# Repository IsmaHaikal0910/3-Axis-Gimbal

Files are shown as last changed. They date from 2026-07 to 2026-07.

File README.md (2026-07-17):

# Camera Gimbal — 3-Axis Stabilization for Smartphones & Cameras

> Custom-built 3-axis camera gimbal (STorM32 BGC + ESP32) with a self-designed 3D-printed frame, wireless shutter control, and a web dashboard for battery/BLE monitoring. Built for a Mechatronics lab project at Jade University of Applied Sciences.

---

## 🇬🇧 English

### Overview
This project is a fully custom 3-axis camera gimbal for smartphones and small action cameras, developed as part of the "Komplexlabor Mechatronik" course at Jade Hochschule Wilhelmshaven (Summer 2026). The goal was to design, build, and validate a handheld gimbal that stabilizes roll, pitch, and yaw in real time, using a mechanically optimized 3D-printed frame and an open, configurable electronics stack instead of a proprietary commercial system (e.g. DJI RS5).

### Key Features
- **3-axis active stabilization** (roll, pitch, yaw) via three iPower GM3506 brushless gimbal motors with AS5048A encoders
- **STorM32 v4.1** BGC controller + **NT IMU v4.2** for orientation sensing and PID-based motor control
- **ESP32** microcontroller handling joystick input, buttons, status LED, and wireless connectivity
- **WLAN/Bluetooth bridge**: a companion phone connects to the ESP32 over Wi-Fi and relays Bluetooth shutter commands to the camera
- **Custom HTML web interface** showing live battery percentage/voltage and providing remote shutter + Bluetooth scan controls
- Self-designed 3D-printed frame (P430 ABS+), removable 11.1 V / 3000 mAh LiPo battery, IP54-rated enclosure target
- Requirements list, circuit diagram, energy-flow diagram, and full verification & validation (V&V) test protocol

### Test Results (summary)
| Test | Result |
|---|---|
| Battery life (215 g payload) | ~2 hours |
| Reaction time (90° step) | 2.46 s (≈36.6°/s) |
| IMU drift (roll/pitch) | No measurable drift |
| Motor thermal | Uncritical after 10–15 min continuous load |
| TRL | 4, approaching 5 |

### Hardware
STorM32 v4.1, NT IMU v4.2, 3× iPower GM3506 gimbal motors, ESP32 (NodeMCU), analog joystick module, 2-button module, RGB status LED, 11.1 V 3000 mAh LiPo + balance charger. Full bill of materials with suppliers and cost is included in the lab report.

### Status & Outlook
The mechanical and electrical integration is complete; PID tuning (especially on the yaw axis) and full closed-loop real-time stabilization are ongoing. Planned next steps include C++/PlatformIO code refactoring with auto-reconnect, mechanical load testing of the screw connections, and empirical battery-life validation under real load.

---

## 🇩🇪 Deutsch

### Überblick
Dieses Projekt ist ein vollständig selbst entwickeltes 3-Achsen-Kamera-Gimbal für Smartphones und kleine Actioncams, entstanden im Rahmen des Komplexlabors Mechatronik an der Jade Hochschule Wilhelmshaven (Sommersemester 2026). Ziel war die Konstruktion, der Aufbau und die Validierung eines Handheld-Gimbals, das Roll-, Pitch- und Yaw-Bewegungen in Echtzeit ausgleicht — mit einem mechanisch optimierten, selbst konstruierten 3D-Druck-Rahmen und einer offenen, konfigurierbaren Elektronik statt eines proprietären kommerziellen Systems (z. B. DJI RS5).

### Hauptmerkmale
- **Aktive 3-Achsen-Stabilisierung** (Roll, Pitch, Yaw) über drei bürstenlose iPower-GM3506-Kardanmotoren mit AS5048A-Encodern
- **STorM32 v4.1** BGC-Controller + **NT IMU v4.2** zur Lageerfassung und PID-basierten Motorregelung
- **ESP32**-Mikrocontroller für Joystick-Eingabe, Taster, Status-LED und drahtlose Kommunikation
- **WLAN/Bluetooth-Brücke**: Ein Mobiltelefon verbindet sich per WLAN mit dem ESP32 und leitet Bluetooth-Auslösebefehle an die Kamera weiter
- **Eigenes HTML-Web-Interface** mit Live-Anzeige von Akkustand/Spannung sowie Fernsteuerung von Auslöser und Bluetooth-Suchlauf
- Selbst konstruierter 3D-Druck-Rahmen (P430 ABS+), entnehmbarer 11,1 V / 3000 mAh LiPo-Akku, Gehäuse ausgelegt auf IP54
- Anforderungsliste, Schaltplan, Energieflussdiagramm sowie ein vollständiges Verifikations- und Validierungs-Testprotokoll (V+V)

### Testergebnisse (Zusammenfassung)
| Test | Ergebnis |
|---|---|
| Akkulaufzeit (215 g Nutzlast) | ca. 2 Stunden |
| Reaktionszeit (90°-Schwenk) | 2,46 s (≈36,6°/s) |
| IMU-Drift (Roll/Pitch) | Keine messbare Drift |
| Motorerwärmung | Unkritisch nach 10–15 Min Dauerbetrieb |
| TRL | 4, an der Schwelle zu 5 |

### Hardware
STorM32 v4.1, NT IMU v4.2, 3× iPower-GM3506-Kardanmotoren, ESP32 (NodeMCU), analoges Joystick-Modul, 2-Tasten-Modul, RGB-Status-LED, 11,1 V 3000 mAh LiPo-Akku mit Balance-Ladegerät. Die vollständige Stückliste mit Lieferanten und Kosten befindet sich im Laborbericht.

### Status & Ausblick
Der mechanische und elektronische Aufbau ist abgeschlossen; die PID-Feinabstimmung (insbesondere der Yaw-Achse) sowie die vollständige Echtzeit-Stabilisierung im geschlossenen Regelkreis sind noch in Arbeit. Geplante nächste Schritte: Code-Refactoring in C++/PlatformIO mit automatischer Wiederverbindung, mechanischer Belastungstest der Schraubverbindungen sowie empirische Validierung der Akkulaufzeit unter realer Last.

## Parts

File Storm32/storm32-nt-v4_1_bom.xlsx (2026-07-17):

storm32-nt-v4 (_1)
index | qty | mounted | name(s) | description | type | value | voltage | tolerance | manufacturer | manufacturer code | jlcpcb
1 | 12 | Yes | C1, C2, C8, C9, ... | capacitor | 0402 (1005 metric) | 0.1uF | 16 | 20 | any | ceramic multilayer | C60474
2 | 2 | Yes | C3, C22 | capacitor | 1210 (3225 metric) | 10uF | 63 | 20 | any | ceramic multilayer | C13585
3 | 1 | Yes | C6 | tantalum capacitor | CASE A | 100uF | 6.3 | 20 | any | tantalum capacitor | C313517
4 | 1 | Yes | L1 | inductor | 4x4 | 10uH |  |  | any | any | C38117
5 | 1 | Yes | U1 | regulator | SOT23-6 | TPS54302 |  |  | Texas Instruments | TPS54302DDCR | C311983
6 | 1 | Yes | C4 | capacitor | 0603 (1608 metric) | 0.1uF | 50 | 10 | any | ceramic multilayer | C14663
7 | 2 | Yes | C5, C7 | capacitor | 0603 (1608 metric) | 10uF | 25 | 20 | any | ceramic multilayer | C19702
8 | 5 | Yes | R4, R6, R8, R9, ... | resistor | 0402 (1005 metric) | 10k | 50 | 1 | any | metal/carbon/thick | C25744
9 | 1 | Yes | R5 | resistor | 0402 (1005 metric) | 75k | 50 | 1 | any | metal/carbon/thick | C25798
10 | 1 | Yes | U3 | MCU | LQFP-64 | STM32F103RCT6 |  |  | STMicroelectronics | STM32F103RCT6 | C8323
11 | 1 | Yes | Q1 | resonator | 3213 | 8MHz |  |  | any | any | C341522
12 | 1 | Yes | LED1 | led | 0603 (1608 metric) | GREEN |  |  | Dialight | 598-8D80-107F | C84264
13 | 1 | Yes | LED2 | led | 0603 (1608 metric) | RED |  |  | Dialight | 598-8D10-107F | C90692
14 | 3 | Yes | D1, D2, D3 | diode | SOD-123 | PMEG3010ER |  |  | Nexperia | PMEG3010ER,115 | C456106
15 | 2 | Yes | J6, J7 | connector | 4-pin | SM04B-SRSS-TB |  |  | JST | SM04B-SRSS-TB(LF)(SN) | C160404
16 | 1 | Yes | J10 | connector | 3-pin | SM03B-SRSS-TB |  |  | JST | SM03B-SRSS-TB(LF)(SN) | C160403
17 | 1 | Yes | U4 | usb-uart | QFN-20 | CP2102N |  |  | Silicon Labs | CP2102N-A02-GQFN20R | C969913
18 | 1 | Yes | R7 | resistor | 0402 (1005 metric) | 1k5 | 50 | 1 | any | metal/carbon/thick | C25867
19 | 1 | Yes | R3 | resistor | 0402 (1005 metric) | 15k | 50 | 1 | any | metal/carbon/thick | C25756
20 | 5 | Yes | U7, U8, U9, U10, ... | driver | WSON-12 | DRV8839 |  |  | Texas Instruments | DRV8839DSSR | C128627
21 | 1 | Yes | U2 | regulator | SOT23-5 | XC6210B332MR |  |  | Torex | XC6210B332MR | C424705
22 | 3 | Yes | R1, R2, R13 | resistor | 0402 (1005 metric) | 2k2 | 50 | 1 | any | metal/carbon/thick | C25879
23 | 1 | Yes | J4 | connector | 7-pin | SM07B-SRSS-TB |  |  | JST | SM07B-SRSS-TB(LF)(SN) | C160393
24 | 1 | Yes | R14 | resistor | 0402 (1005 metric) | 4k7 | 50 | 1 | any | metal/carbon/thick | C25900
25 | 1 | Yes | U6 | xor | SOT23-5 | 74AHC1G86 |  |  | Texas Instruments | SN74AHC1G86DBVR | C7471
26 | 2 | Yes | C13, C15 | capacitor | 0402 (1005 metric) | 4.7uF | 6.3 | 20 | any | ceramic multilayer | C23733
27 | 1 | Yes | C12 | capacitor | 0402 (1005 metric) | 10nF | 16 | 10 | any | ceramic multilayer | C15195
28 | 1 | Yes | U5 | imu | SMD | ICM42688 |  |  | TDK InvenSense | ICM-42688-P | C1850418
29 | 1 | Yes | J3 | usb-c | smd/tht | usb-c |  |  | Dealon | USB-TYPE-C-16P | C668624
30 | 1 | Yes | J5 | connector | 5-pin | SM05B-SRSS-TB |  |  | JST | SM05B-SRSS-TB(LF)(SN) | C136657
31 | 2 | Yes | R10, R11 | resistor | 0402 (1005 metric) | 5k1 | 50 | 1 | any | metal/carbon/thick | C25905
32 | 1 | Yes | C10 | capacitor | 0402 (1005 metric) | 2.2uF | 6.3 | 20 | any | ceramic multilayer | C12530

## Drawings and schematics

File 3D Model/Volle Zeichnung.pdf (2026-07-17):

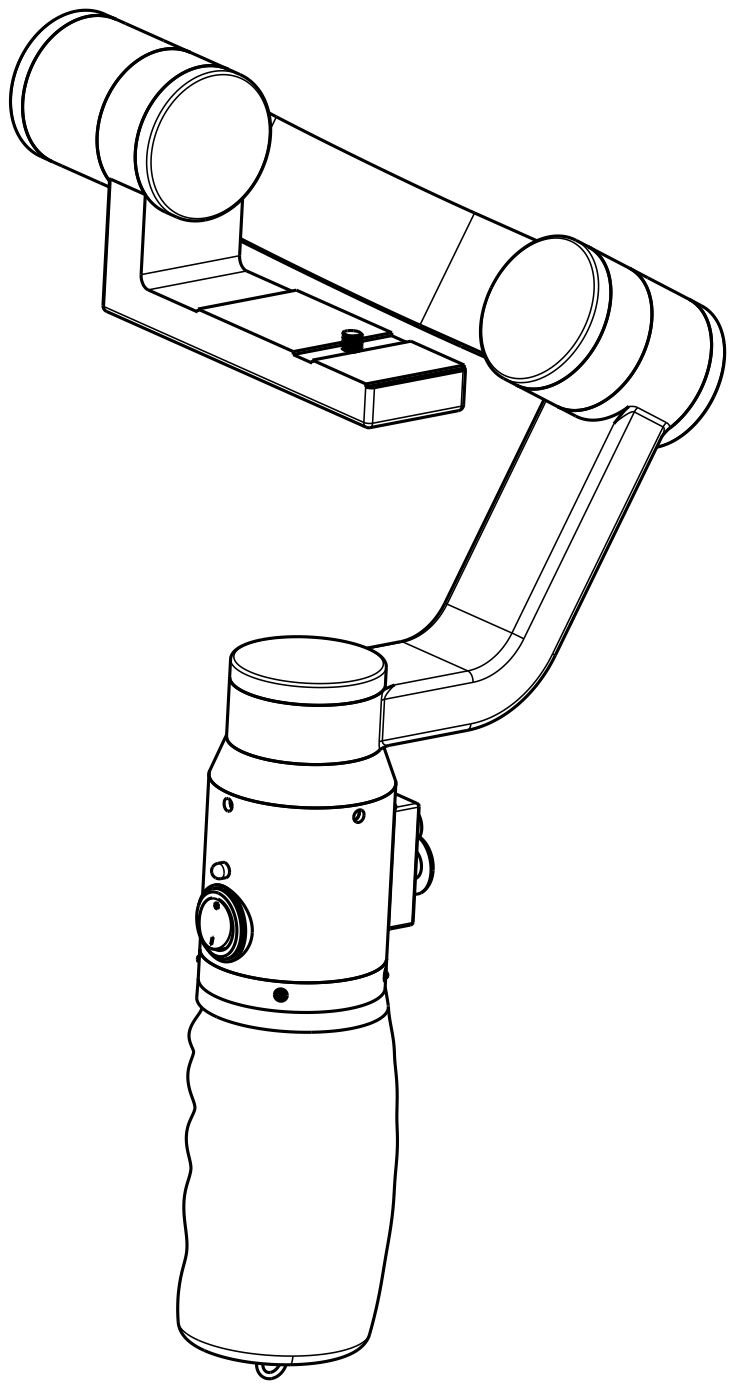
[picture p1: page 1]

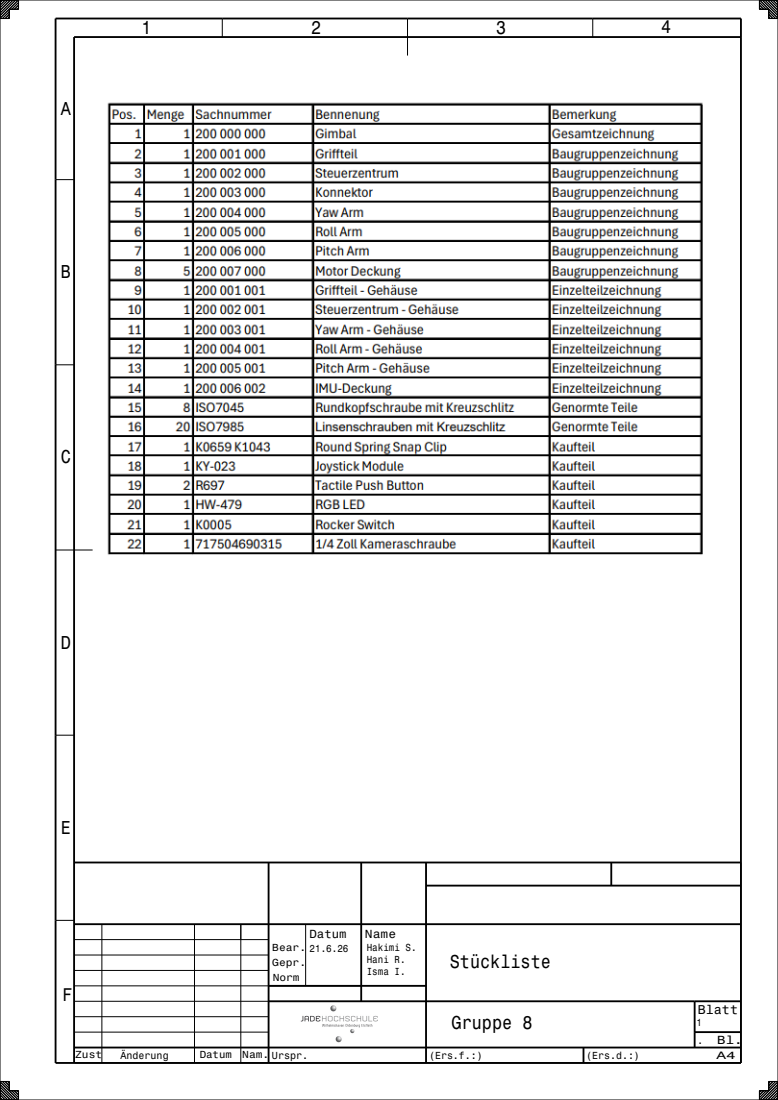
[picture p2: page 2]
Gruppe 8; Hakimi S. Hani R. Isma I.; Zust; Änderung; Datum; Nam. Urspr.

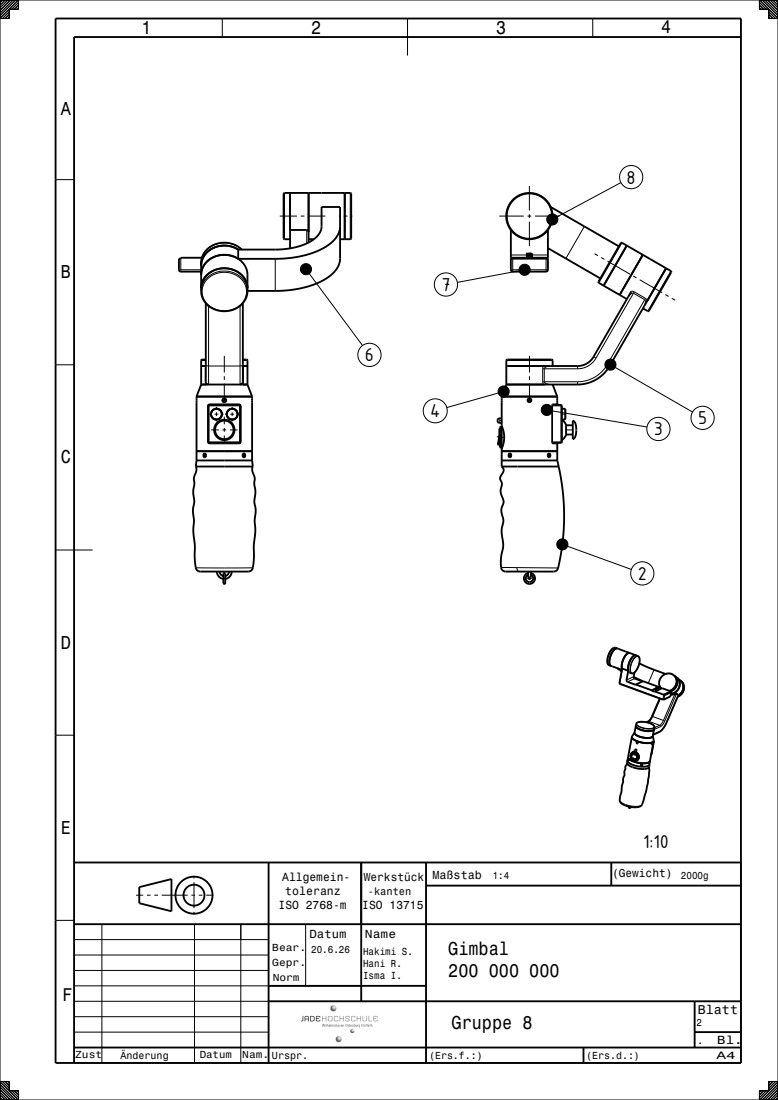
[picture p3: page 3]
ISO 2768-m; ISO 13715; (Gewicht) 2000g; Maßstab 1:4; Hakimi S. Hani R. Isma I.

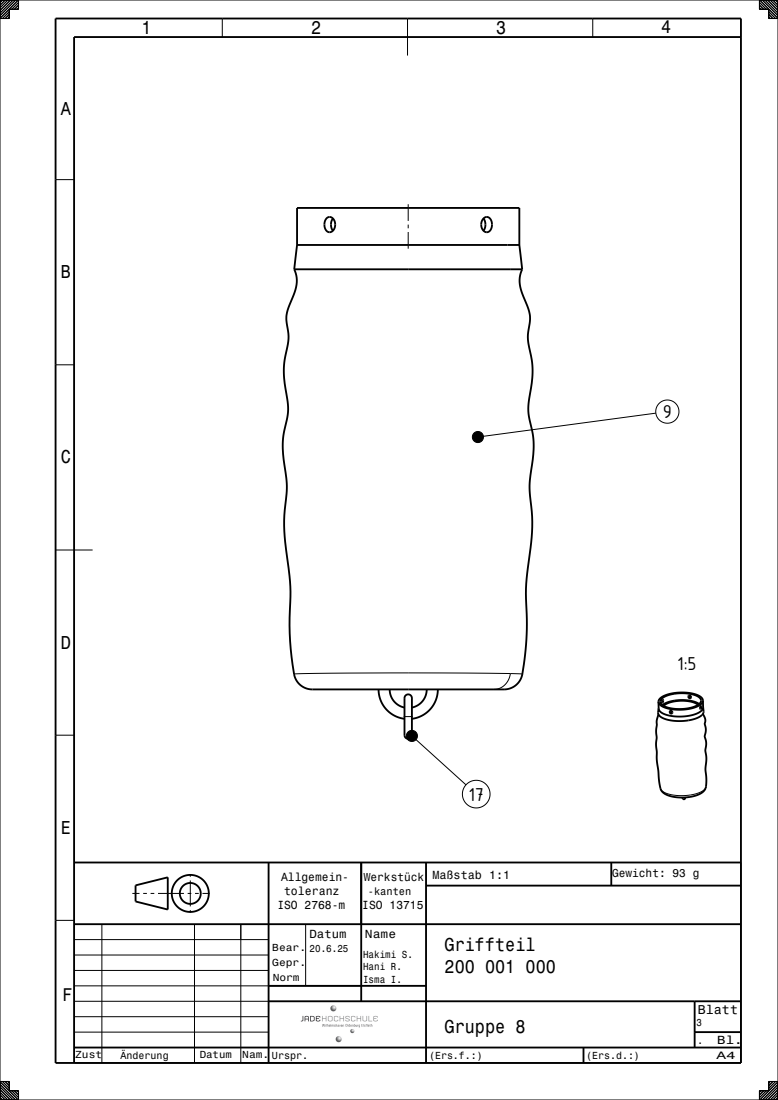
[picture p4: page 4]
ISO 2768-m; ISO 13715; Gewicht: 93 g; Maßstab 1:1; Hakimi S. Hani R. Isma I.

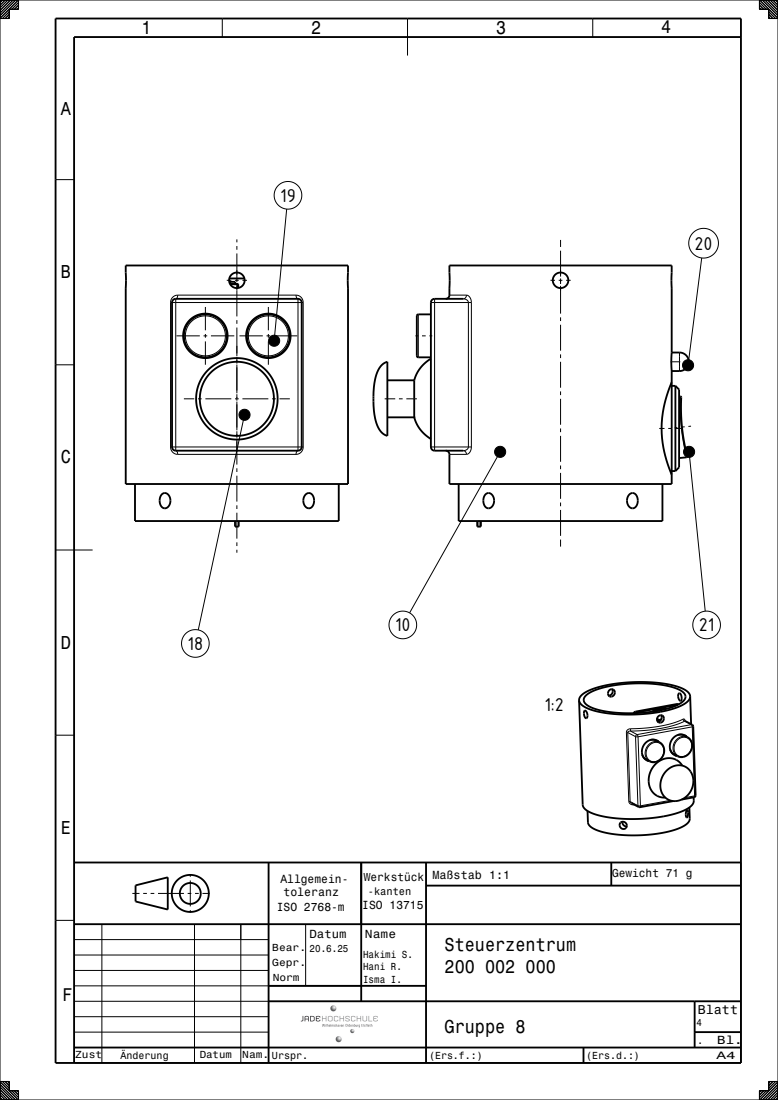
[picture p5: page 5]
ISO 2768-m; ISO 13715; Gewicht 71 g; Maßstab 1:1; Hakimi S. Hani R. Isma I.

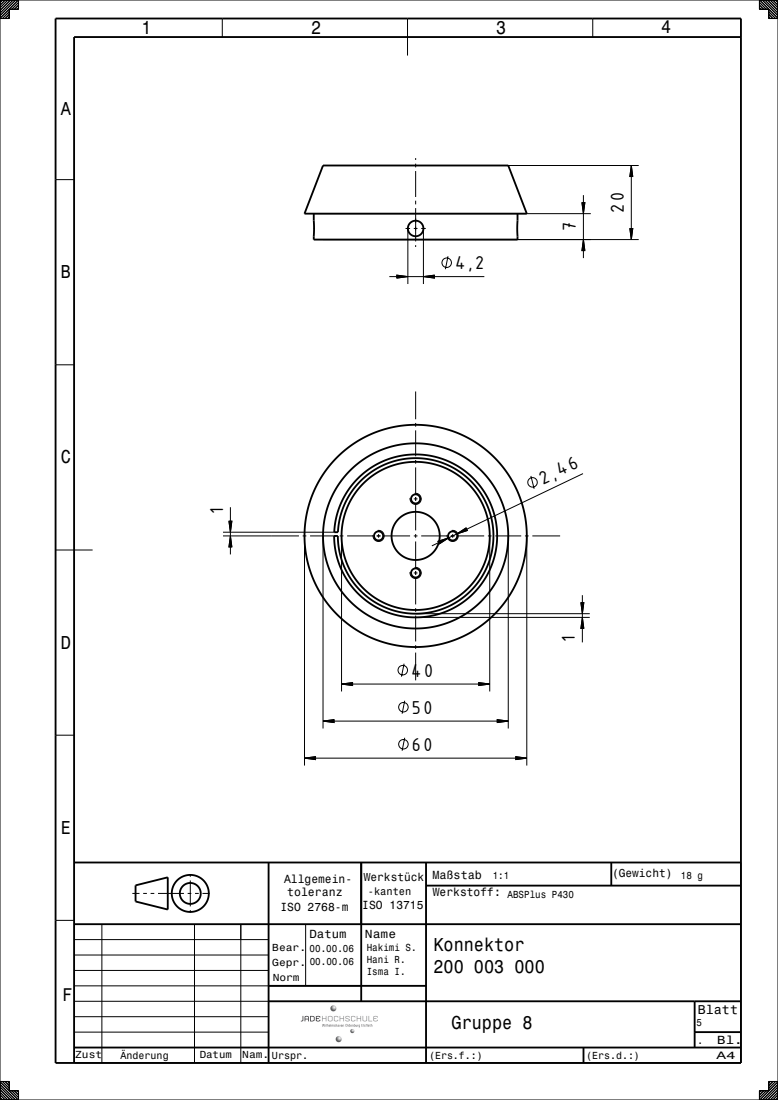
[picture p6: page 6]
ISO 2768-m; ISO 13715; (Gewicht) 18 g; Werkstoff: ABSPlus P430; Maßstab 1:1; Hakimi S. Hani R. Isma I.

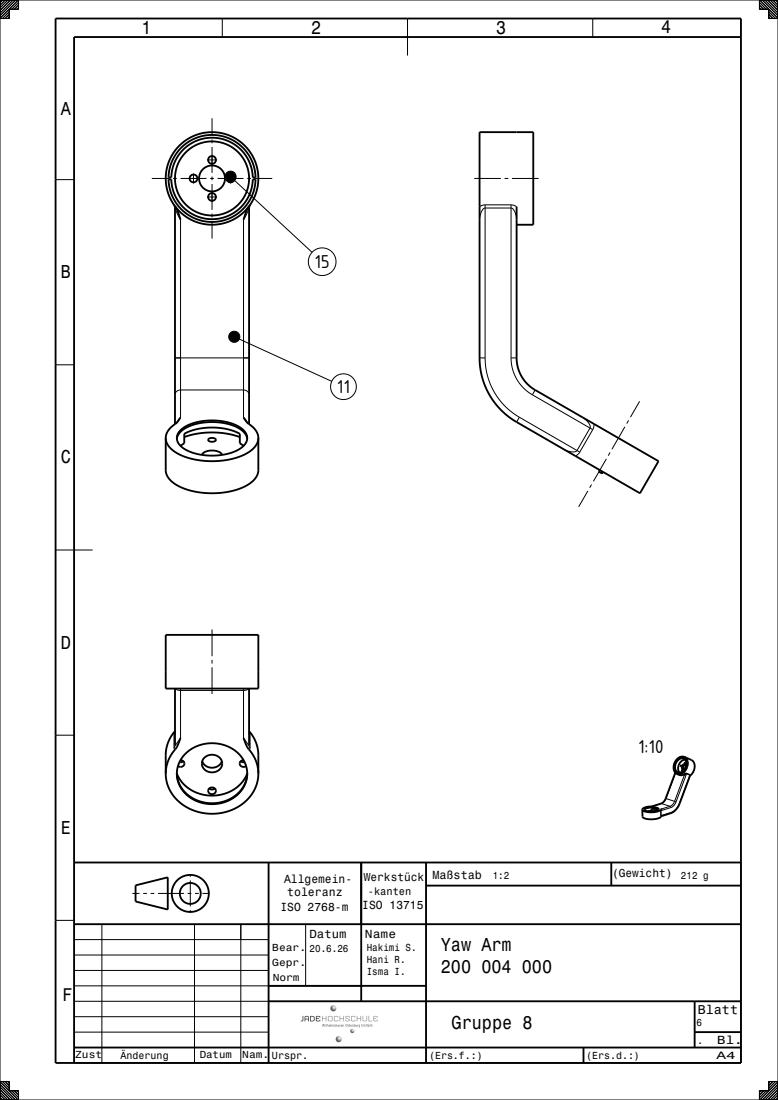
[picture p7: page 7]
ISO 2768-m; ISO 13715; (Gewicht) 212 g; Yaw Arm 200 004 000; Maßstab 1:2; Hakimi S. Hani R. Isma I.

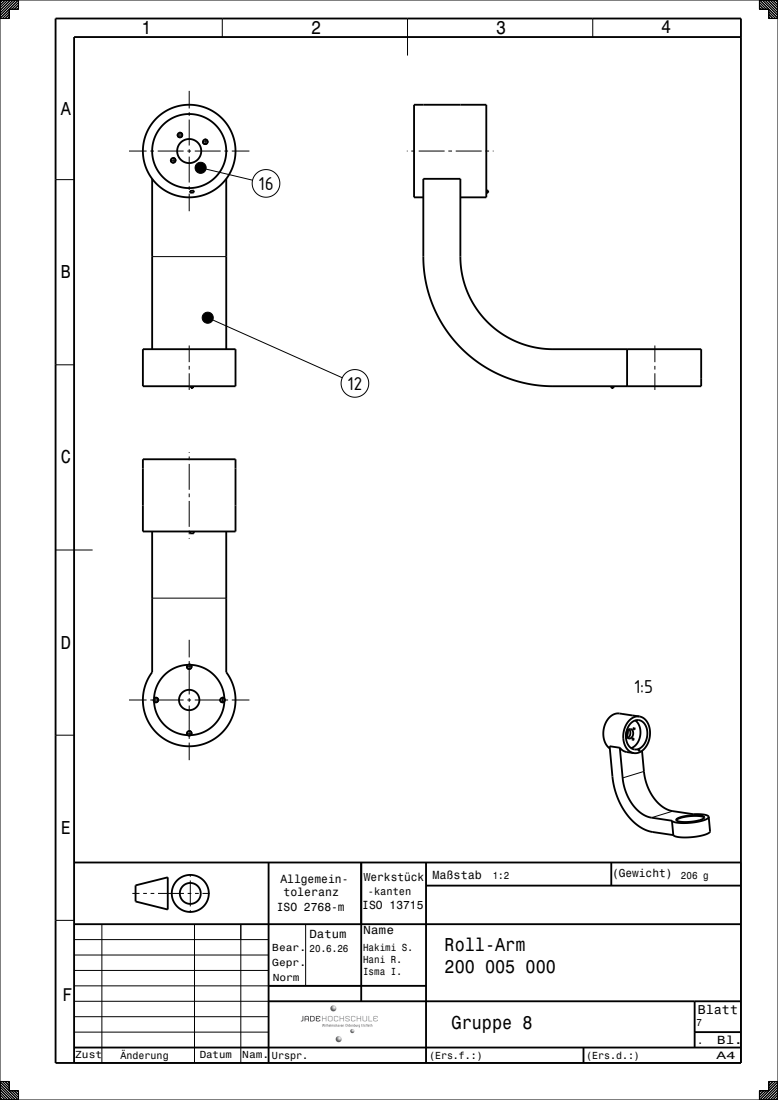
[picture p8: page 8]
ISO 2768-m; ISO 13715; (Gewicht) 206 g; Maßstab 1:2; Hakimi S. Hani R. Isma I.

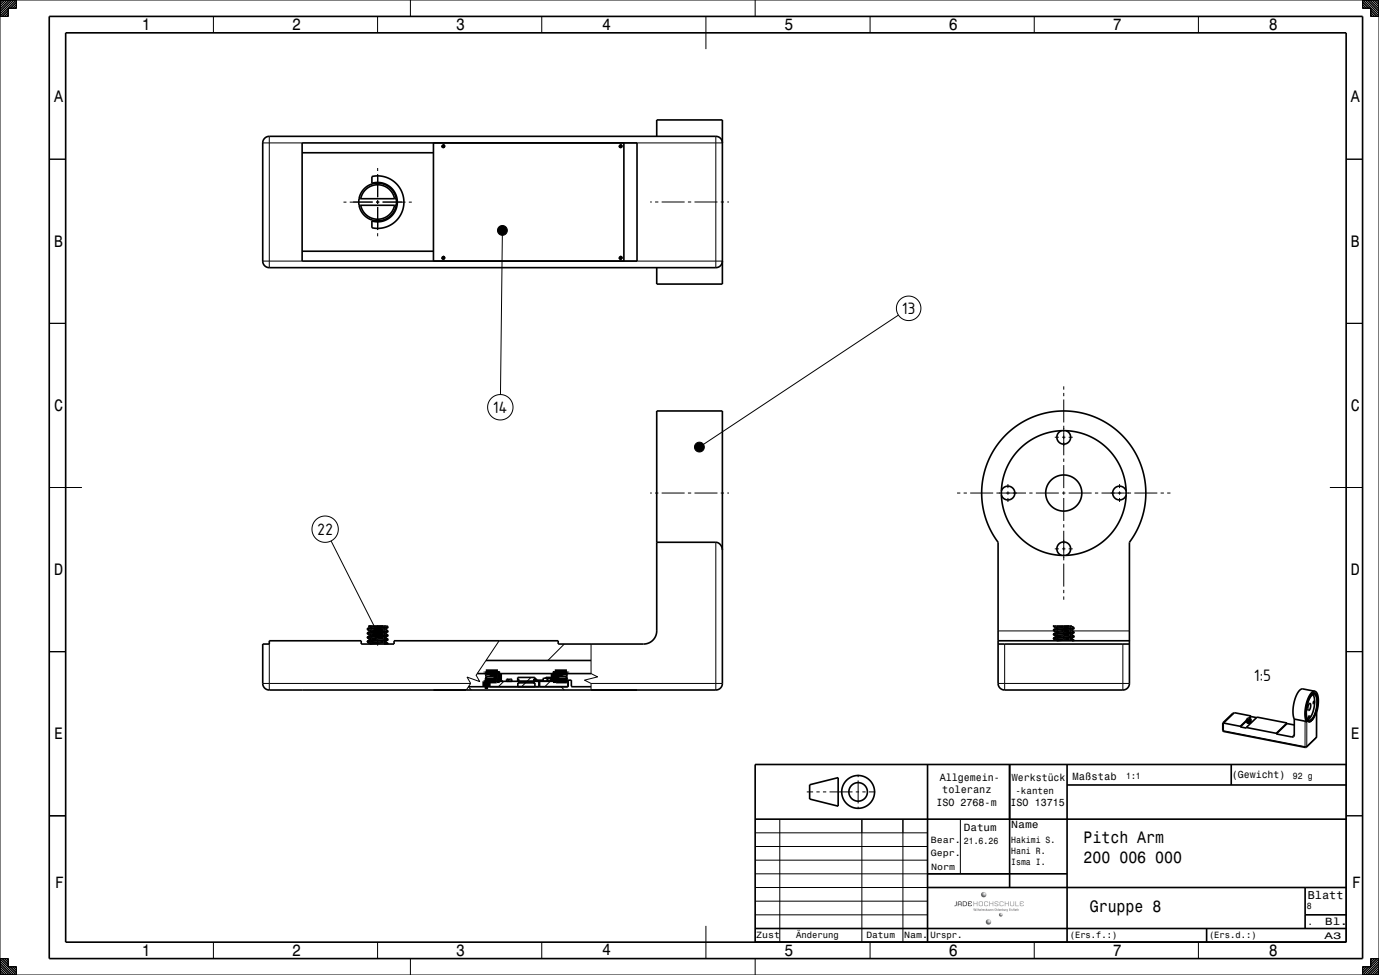
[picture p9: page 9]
ISO 2768-m; ISO 13715; (Gewicht) 92 g; Pitch Arm 200 006 000; Maßstab 1:1; Hakimi S. Hani R. Isma I.

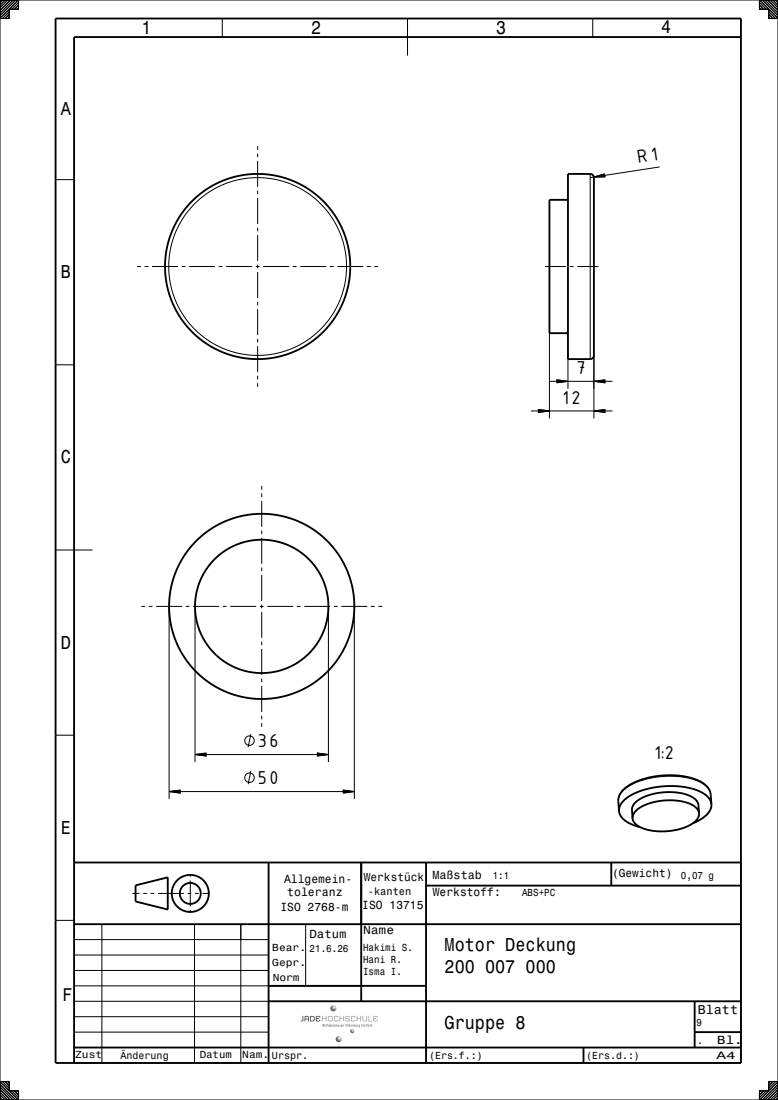
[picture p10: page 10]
ISO 2768-m; ISO 13715; (Gewicht) 0,07 g; Motor Deckung 200 007 000; Maßstab 1:1; Hakimi S. Hani R. Isma I.

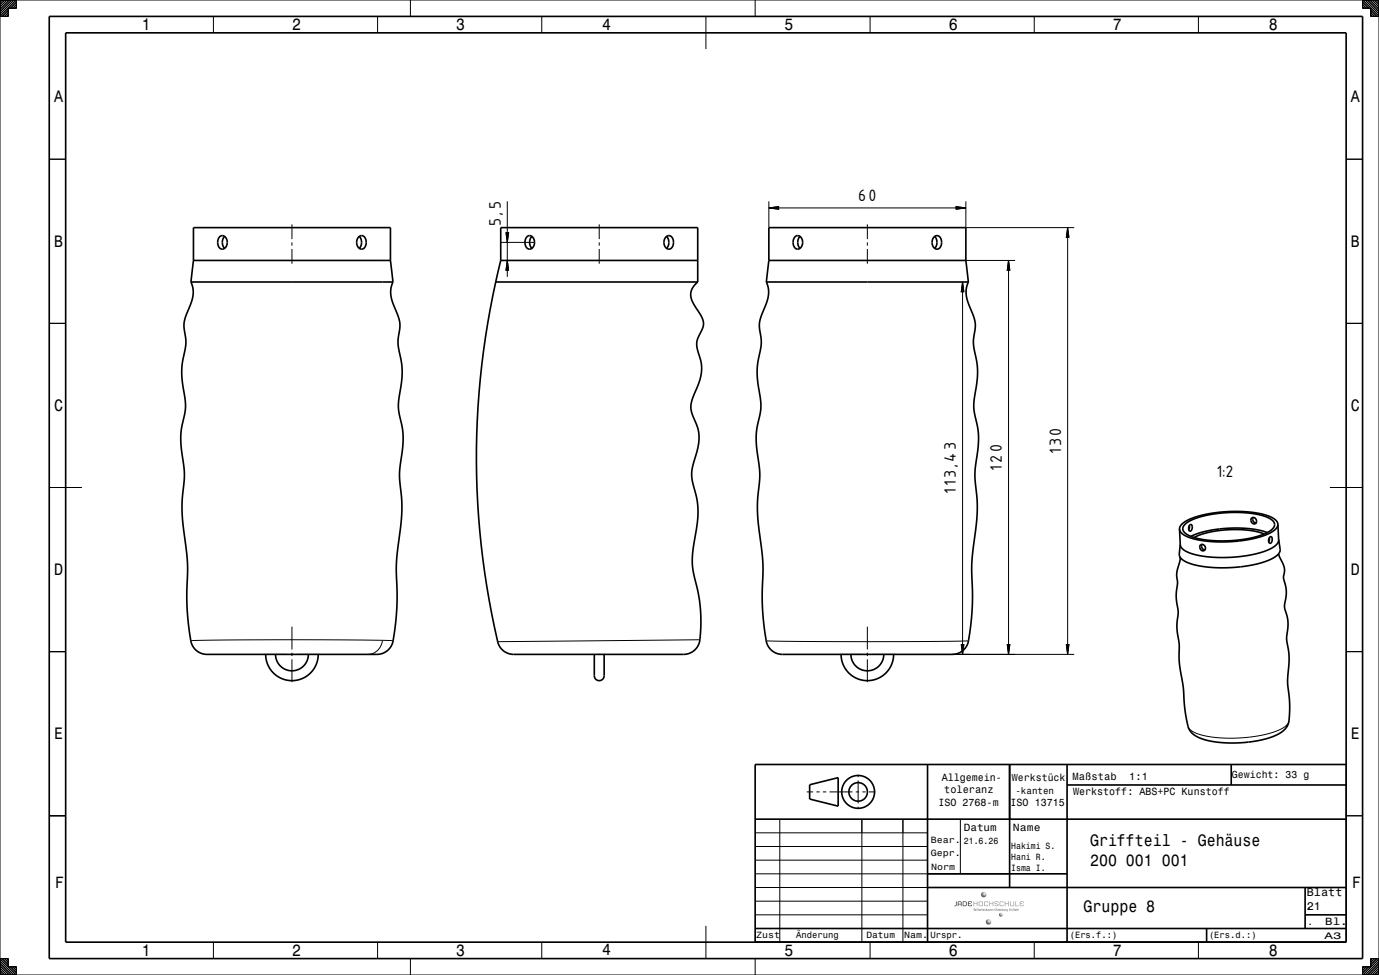
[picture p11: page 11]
ISO 2768-m; ISO 13715; Gewicht: 33 g

Maßstab 1:1
Werkstoff: ABS+PC Kunstoff

Bear. Gepr. Norm | Datum 21.6.26 | Name Hakimi S. Hani R. Isma I. | Griffteil - Gehäuse 200 001 001

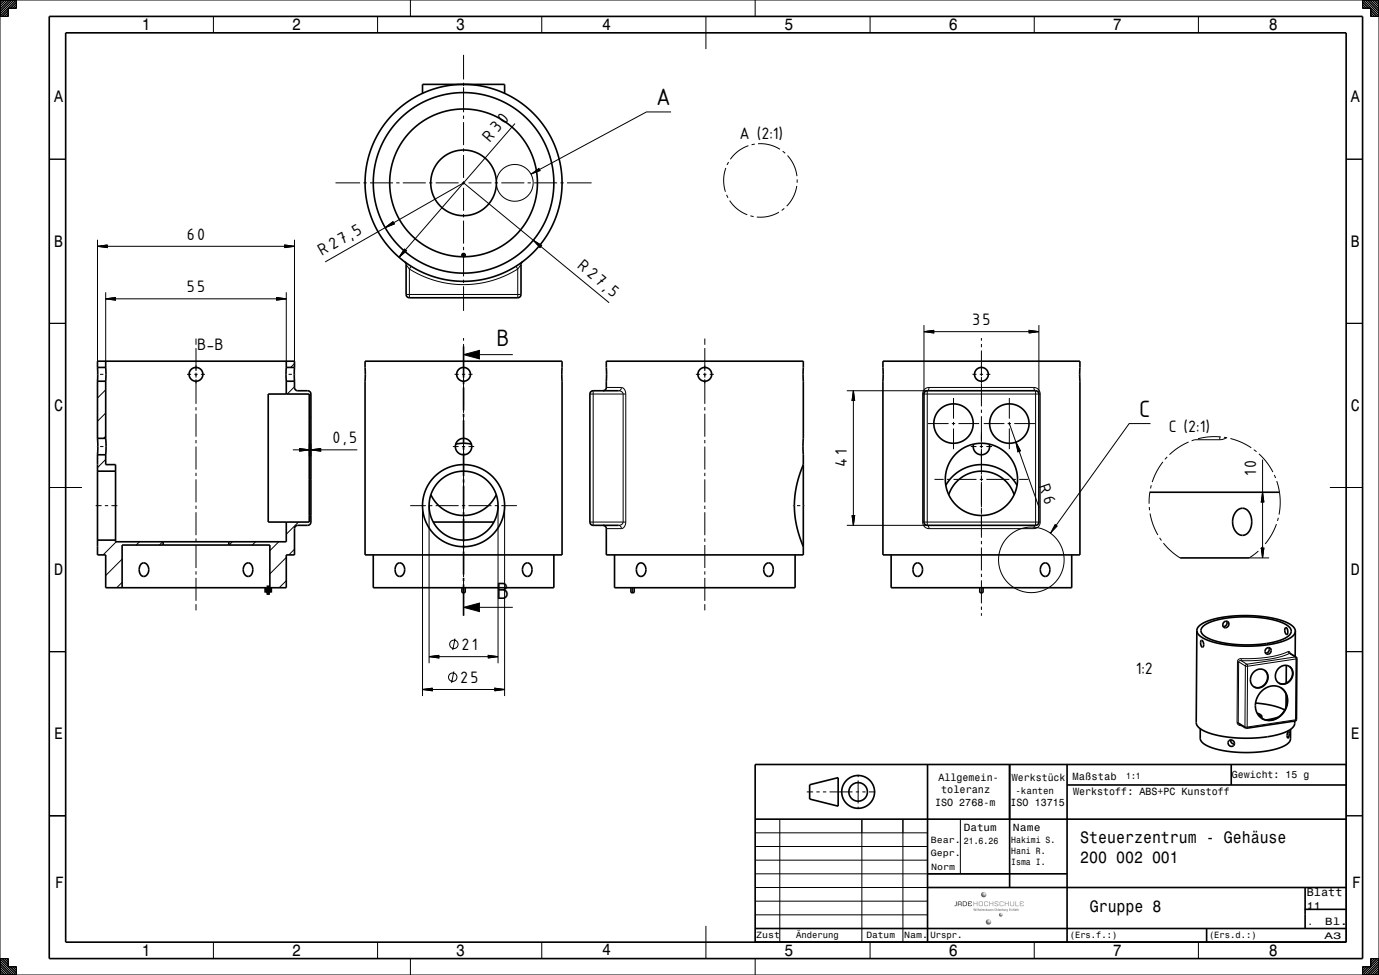
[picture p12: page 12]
ISO 2768-m; ISO 13715; Gewicht: 15 g; Steuerzentrum - Gehäuse 200 002 001; Hakimi S. Hani R. Isma I.

Maßstab 1:1
Werkstoff: ABS+PC Kunstoff

ISO 2768-m; ISO 13715; (Gewicht) 208g; Werkstoff:; ABSPlus P430; Maßstab 1:1; Hakimi S. Hani R. Isma I.

Yaw Arm - Gehäuse

ISO 2768-m; ISO 13715; (Gewicht) 126 g; Werkstoff:; ABS + PC Kunstoff; Maßstab 1:1

Bear. Gepr. Norm | Datum 02.06.25 | Name Hakimi S. Hani R. Isma I. | Roll-Arm Gehäuse 200 004 001

ISO 2768-m; ISO 13715; (Gewicht) 76 g; Werkstoff:; ABS+ PC; Maßstab 1:1; Hakimi S. Hani R. Isma I.

Pitch Arm - Gehäuse

ISO 2768-m; ISO 13715; (Gewicht) 0,6 g; Gruppe 8'; Maßstab 1:1; Hakimi S. Hani R. Isma I.

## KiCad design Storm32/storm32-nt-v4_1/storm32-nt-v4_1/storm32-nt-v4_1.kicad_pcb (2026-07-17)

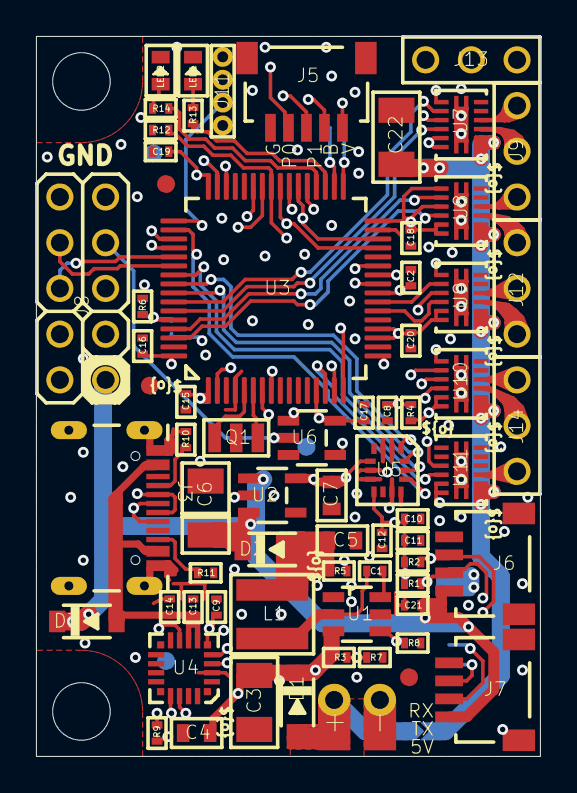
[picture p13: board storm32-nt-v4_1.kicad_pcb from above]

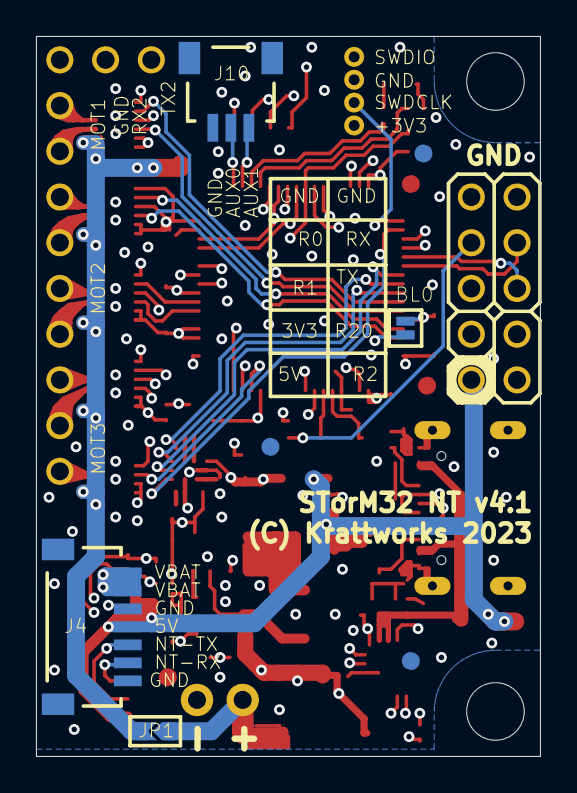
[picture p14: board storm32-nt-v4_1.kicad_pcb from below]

Board: 4 copper layers, 28.0 x 40.0 mm, 79 parts (7 on the bottom side), 69 nets.

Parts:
BL0: BOOT0; __SPARKFUN2_SJ_2S-NO
C1, C2, C8, C9, C11, C14, C16, C17, C18, C19, C20, C21: 0.1uF; 0402[1005-METRIC]
C3, C22: 10uF; 1206[3216-METRIC]
C4: 0.1uF; 0603[1608-METRIC]
C5, C7: 10uF; 0603[1608-METRIC]
C6: 100uF; 1206[3216-METRIC]-POL
C10: 2.2uF; 0402[1005-METRIC]
C12: 10nF; 0402[1005-METRIC]
C13, C15: 4.7uF; 0402[1005-METRIC]
D1, D2, D3: PMEG3010ER; SOD-123
FIDUCIAL1, FIDUCIAL2, FIDUCIAL3, FIDUCIAL4, FIDUCIAL5, FIDUCIAL6: FIDUCIAL
FRAMEBRD1: A5L-LOC
J1: +; 1
J2: -; 1
J3: TYPE-C-16P
J4: SM07B-SRSS-TB
J5: SM05B-SRSS-TB
J6, J7: SM04B-SRSS-TB
J8: HEADER; 2X5
J9, J12, J13, J14: HEADER_THT_2.54X1N_MALE-03
J10: SM03B-SRSS-TB
J11: HEADER_THT_1.27X1N_MALE-04
JP1: N/A; 0603[1608-METRIC]-0OHM-OFF
L1: 10uH; 4X4
LED1: GREEN; 0603[1608-METRIC]-DIODE
LED2: RED; 0603[1608-METRIC]-DIODE
Q1: 8MHz; RESONATOR
R1, R2, R13: 2k2; 0402[1005-METRIC]
R3: 15k; 0402[1005-METRIC]
R4, R6, R8, R9, R12: 10k; 0402[1005-METRIC]
R5: 75k; 0402[1005-METRIC]
R7: 1k5; 0402[1005-METRIC]
R10, R11: 5k1; 0402[1005-METRIC]
R14: 4k7; 0402[1005-METRIC]
U1: TPS54302; SOT-23-6
U2: XC6210B332MR; SOT-23-5
U3: STM32F103RCT6; QFP50P1200X1200X160-64N
U4: CP2102N; QFN-20
U5: ICM42688; LGA14
U6: 74AHC1G86; SOT-23-5
U7, U8, U9, U10, U11: DRV8839; WSON12
UNK_HOLE_0: dummyfp0
UNK_HOLE_1: dummyfp1

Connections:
+3V3: BL0.2, C7.P$1, C10.P$1, C11.P$1, C12.P$1, C15.P$1, C16.P$1, C17.P$1, C18.P$1, C19.P$1, C20.P$1, J5.1, J8.8, J11.1, R1.P$1, R2.P$1, R4.P$2, U2.5, U3.1, U3.13, U3.19, U3.20, U3.32, U3.48, U3.64, U5.5, U5.8, U6.5, U7.7, U7.9, U7.11, U7.12, U8.7, U8.9, U8.11, U8.12, U9.7, U9.9, U9.11, U9.12, U10.7, U10.9, U10.11, U10.12, U11.9, U11.11, U11.12
+5V: C6.P, C21.P$1, D2.C, D3.C, J4.4, J6.1, J7.1, J8.10, U2.1, U2.3
/CS: U3.50, U5.12
AUX0: J10.2, U3.33
AUX1: J10.1, U3.34
BUT: J5.2, U3.25
GND: C2.P$2, C3.P$2, C4.P$2, C5.P$2, C6.N, C7.P$2, C8.P$2, C9.P$2, C10.P$2, C11.P$2, C12.P$2, C13.P$2, C14.P$2, C15.P$2, C16.P$2, C17.P$2, C18.P$2, C19.P$2, C20.P$2, C21.P$2, C22.P$2, J2.1, J2.1A, J3.A1, J3.A12, J3.B1, J3.B12, J3.G1, J3.G2, J3.G3, J3.G4, J4.3, J4.7, J4.FIT@1, J4.FIT@2, J5.5, J5.FIT@1, J5.FIT@2, J6.4, J6.FIT@1, J6.FIT@2, J7.4, J7.FIT@1, J7.FIT@2, J8.1, J8.2, J10.3, J10.FIT@1, J10.FIT@2, J11.3, J13.1, LED1.C, LED2.C, Q1.G, R6.P$1, R7.P$1, R8.P$1, R10.P$2, R11.P$2, R12.P$2, U1.1, U2.2, U3.4, U3.12, U3.18, U3.28, U3.31, U3.47, U3.63, U4.3, U4.12, U5.2, U5.3, U5.6, U5.7, U5.10, U5.11, U6.3, U7.5, U7.6, U7.GND1, U7.GND2, U7.GND3, U7.GND4, U7.GND5, U8.5, U8.6, U8.GND1, U8.GND2, U8.GND3, U8.GND4, U8.GND5, U9.5, U9.6, U9.GND1, U9.GND2, U9.GND3, U9.GND4, U9.GND5, U10.5, U10.6, U10.GND1, U10.GND2, U10.GND3, U10.GND4, U10.GND5, U11.5, U11.6, U11.7, U11.8, U11.GND1, U11.GND2, U11.GND3, U11.GND4, U11.GND5
LED0: R13.P$2, U3.35
LED1: R14.P$2, U3.36
LIPO: C2.P$1, R3.P$1, R7.P$2, U3.24
M-A1: U3.58, U7.8
M-A2: U3.59, U7.10
M-A3: U3.61, U8.8
M-B1: U3.62, U8.10
M-B2: U3.23, U9.8
M-B3: U3.22, U9.10
M-C1: U3.26, U10.8
M-C2: U3.15, U10.10
M-C3: U3.14, U11.10
MISO: U3.56, U5.1
MOSI: U3.57, U5.14
unnamed: J3.A5, R10.P$1
unnamed: J3.B5, R11.P$1
unnamed: C1.P$1, L1.1, U1.2
unnamed: Q1.1, U3.6
unnamed: Q1.2, U3.5
unnamed: C8.P$1, R4.P$1, U3.7
unnamed: C1.P$2, U1.6
unnamed: LED1.A, R13.P$1
unnamed: J3.A6, J3.B6, U4.4
unnamed: J3.A7, J3.B7, U4.5
unnamed: C13.P$1, C14.P$1, D3.A, J3.A4, J3.A9, J3.B4, J3.B9, U4.7, U4.8
unnamed: R9.P$2, U4.9
unnamed: R5.P$1, R8.P$2, U1.4
unnamed: C22.P$1, JP1.P$2, U7.1, U7.2, U8.1, U8.2, U9.1, U9.2, U10.1, U10.2, U11.1, U11.2
unnamed: C5.P$1, D2.A, L1.2, R5.P$2
unnamed: LED2.A, R14.P$1
unnamed: J9.1, U7.4
unnamed: J9.2, U7.3
unnamed: J9.3, U8.4
unnamed: J12.1, U8.3
unnamed: J12.2, U9.4
unnamed: J12.3, U9.3
unnamed: J14.2, U10.3
unnamed: J14.1, U10.4
unnamed: BL0.1, R6.P$2, U3.60
unnamed: J14.3, U11.3
NT_RX: J4.6, J6.3, J7.3, R2.P$2, U3.52
NT_TX: J4.5, J6.2, J7.2, R1.P$2, U3.51
POT0: J5.4, U3.27
POT1: J5.3, U3.8
RC0/RX3: U3.30, U3.38, U6.4
RC2-0: J8.7, U3.39
RC-0: J8.4, U6.2
RC-1: J8.6, U3.29, U3.40
RC-2: J8.9, U3.37
RX1: U3.43, U4.18
RX2: J13.2, U3.17
RX5: J8.3, U3.54
SCK: U3.55, U5.13
SWC: J11.2, U3.49
SWD: J11.4, U3.46
TX1: U3.42, U4.17
TX2: J13.3, U3.16
TX5: J8.5, U3.53
USB_DETECT: C9.P$1, R9.P$1, U3.2, U4.6
VBAT: C3.P$1, C4.P$1, D1.C, J4.1, J4.2, R3.P$2, U1.3
VIN: D1.A, J1.1, J1.1A, JP1.P$1
XOR: R12.P$1, U3.41, U6.1

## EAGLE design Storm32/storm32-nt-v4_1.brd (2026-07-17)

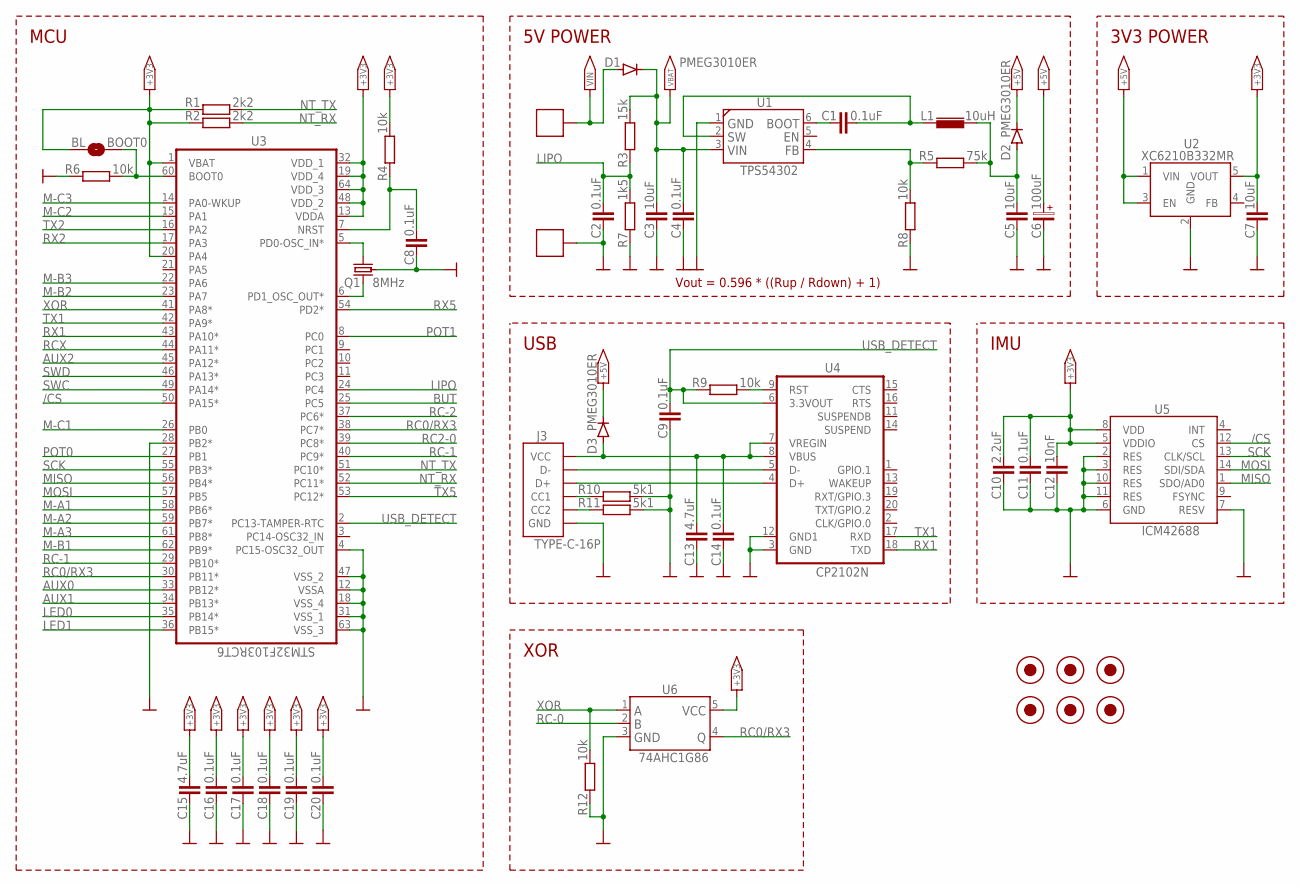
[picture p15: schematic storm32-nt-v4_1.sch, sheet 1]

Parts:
BL: BOOT0; __SPARKFUN2_SJ_2S-NO
C1, C2, C8, C9, C11, C14, C16, C17, C18, C19, C20: 0.1uF; 0402[1005-METRIC]
C3: 10uF; 1206[3216-METRIC]; VOLTAGE 63; MOUSER 81-GRM32ER71J106MA2L
C4: 0.1uF; 0603[1608-METRIC]
C5, C7: 10uF; 0603[1608-METRIC]
C6: 100uF; 1206[3216-METRIC]-POL
C10: 2.2uF; 0402[1005-METRIC]
C12: 10nF; 0402[1005-METRIC]
C13, C15: 4.7uF; 0402[1005-METRIC]
D1, D2, D3: PMEG3010ER; SOD-123
FIDUCIAL1, FIDUCIAL2, FIDUCIAL3, FIDUCIAL4, FIDUCIAL5, FIDUCIAL6: FIDUCIAL
J1: +; 1
J2: -; 1
J3: TYPE-C-16P
L1: 10uH; 4X4
Q1: 8MHz; RESONATOR
R1, R2: 2k2; 0402[1005-METRIC]
R3: 15k; 0402[1005-METRIC]
R4, R6, R8, R9, R12: 10k; 0402[1005-METRIC]
R5: 75k; 0402[1005-METRIC]
R7: 1k5; 0402[1005-METRIC]
R10, R11: 5k1; 0402[1005-METRIC]
U1: TPS54302; SOT-23-6
U2: XC6210B332MR; SOT-23-5
U3: STM32F103RCT6; QFP50P1200X1200X160-64N
U4: CP2102N; QFN-20
U5: ICM42688; LGA14
U6: 74AHC1G86; SOT-23-5

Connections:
+3V3: BL.2, C7.P$1 (1), C10.P$1 (1), C11.P$1 (1), C12.P$1 (1), C15.P$1 (1), C16.P$1 (1), C17.P$1 (1), C18.P$1 (1), C19.P$1 (1), C20.P$1 (1), R1.P$1, R2.P$1, R4.P$2, U2.5 (VOUT), U3.1 (VBAT), U3.13 (VDDA), U3.19 (VDD_4), U3.20 (PA4), U3.32 (VDD_1), U3.48 (VDD_2), U3.64 (VDD_3), U5.5 (VDDIO), U5.8 (VDD), U6.5; also elsewhere on the board
+5V: C6.P, D2.C, D3.C, U2.1 (VIN), U2.3 (EN); also elsewhere on the board
/CS: U3.50 (PA15*), U5.12 (CS)
AUX0: U3.33 (PB12*); also elsewhere on the board
AUX1: U3.34 (PB13*); also elsewhere on the board
AUX2: U3.45 (PA12*)
BUT: U3.25 (PC5); also elsewhere on the board
GND: C2.P$2 (2), C3.P$2 (2), C4.P$2 (2), C5.P$2 (2), C6.N, C7.P$2 (2), C8.P$2 (2), C9.P$2 (2), C10.P$2 (2), C11.P$2 (2), C12.P$2 (2), C13.P$2 (2), C14.P$2 (2), C15.P$2 (2), C16.P$2 (2), C17.P$2 (2), C18.P$2 (2), C19.P$2 (2), C20.P$2 (2), J2.1, J2.1A, J3.A1 (GND), J3.A12 (GND), J3.B1 (GND), J3.B12 (GND), J3.G1 (GND), J3.G2 (GND), J3.G3 (GND), J3.G4 (GND), Q1.G (GND), R6.P$1, R7.P$1, R8.P$1, R10.P$2, R11.P$2, R12.P$2, U1.1, U2.2 (GND), U3.4 (PC15-OSC32_OUT), U3.12 (VSSA), U3.18 (VSS_4), U3.28 (PB2*), U3.31 (VSS_1), U3.47 (VSS_2), U3.63 (VSS_3), U4.3 (GND), U4.12 (GND1), U5.2 (RES), U5.3 (RES), U5.6 (GND), U5.7 (RESV), U5.10 (RES), U5.11 (RES), U6.3; also elsewhere on the board
LED0: U3.35 (PB14*); also elsewhere on the board
LED1: U3.36 (PB15*); also elsewhere on the board
LIPO: C2.P$1 (1), R3.P$1, R7.P$2, U3.24 (PC4)
M-A1: U3.58 (PB6*); also elsewhere on the board
M-A2: U3.59 (PB7*); also elsewhere on the board
M-A3: U3.61 (PB8*); also elsewhere on the board
M-B1: U3.62 (PB9*); also elsewhere on the board
M-B2: U3.23 (PA7); also elsewhere on the board
M-B3: U3.22 (PA6); also elsewhere on the board
M-C1: U3.26 (PB0); also elsewhere on the board
M-C2: U3.15 (PA1); also elsewhere on the board
M-C3: U3.14 (PA0-WKUP); also elsewhere on the board
MISO: U3.56 (PB4*), U5.1 (SDO/AD0)
MOSI: U3.57 (PB5), U5.14 (SDI/SDA)
unnamed: J3.A5 (CC1), R10.P$1
unnamed: J3.B5 (CC2), R11.P$1
unnamed: C1.P$1 (1), L1.1, U1.2
unnamed: Q1.1, U3.6 (PD1_OSC_OUT*)
unnamed: Q1.2, U3.5 (PD0-OSC_IN*)
unnamed: C8.P$1 (1), R4.P$1, U3.7 (NRST)
unnamed: C1.P$2 (2), U1.6
unnamed: J3.A6 (D+), J3.B6 (D+), U4.4 (D+)
unnamed: J3.A7 (D-), J3.B7 (D-), U4.5 (D-)
unnamed: C13.P$1 (1), C14.P$1 (1), D3.A, J3.A4 (VCC), J3.A9 (VCC), J3.B4 (VCC), J3.B9 (VCC), U4.7 (VREGIN), U4.8 (VBUS)
unnamed: R9.P$2, U4.9 (RST)
unnamed: R5.P$1, R8.P$2, U1.4
unnamed: C5.P$1 (1), D2.A, L1.2, R5.P$2
unnamed: BL.1, R6.P$2, U3.60 (BOOT0)
NT_RX: R2.P$2, U3.52 (PC11*); also elsewhere on the board
NT_TX: R1.P$2, U3.51 (PC10*); also elsewhere on the board
POT0: U3.27 (PB1); also elsewhere on the board
POT1: U3.8 (PC0); also elsewhere on the board
RC0/RX3: U3.30 (PB11*), U3.38 (PC7*), U6.4
RC2-0: U3.39 (PC8*); also elsewhere on the board
RC-0: U6.2; also elsewhere on the board
RC-1: U3.29 (PB10*), U3.40 (PC9*); also elsewhere on the board
RC-2: U3.37 (PC6*); also elsewhere on the board
RCX: U3.44 (PA11*)
RX1: U3.43 (PA10*), U4.18 (TXD)
RX2: U3.17 (PA3); also elsewhere on the board
RX5: U3.54 (PD2*); also elsewhere on the board
SCK: U3.55 (PB3*), U5.13 (CLK/SCL)
SWC: U3.49 (PA14*); also elsewhere on the board
SWD: U3.46 (PA13*); also elsewhere on the board
TX1: U3.42 (PA9*), U4.17 (RXD)
TX2: U3.16 (PA2); also elsewhere on the board
TX5: U3.53 (PC12*); also elsewhere on the board
USB_DETECT: C9.P$1 (1), R9.P$1, U3.2 (PC13-TAMPER-RTC), U4.6 (3.3VOUT)
VBAT: C3.P$1 (1), C4.P$1 (1), D1.C, R3.P$2, U1.3; also elsewhere on the board
VIN: D1.A, J1.1, J1.1A; also elsewhere on the board
XOR: R12.P$1, U3.41 (PA8*), U6.1

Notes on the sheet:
Vout = 0.596 * ((Rup / Rdown) + 1)
5V POWER
USB
3V3 POWER
MCU
IMU
XOR

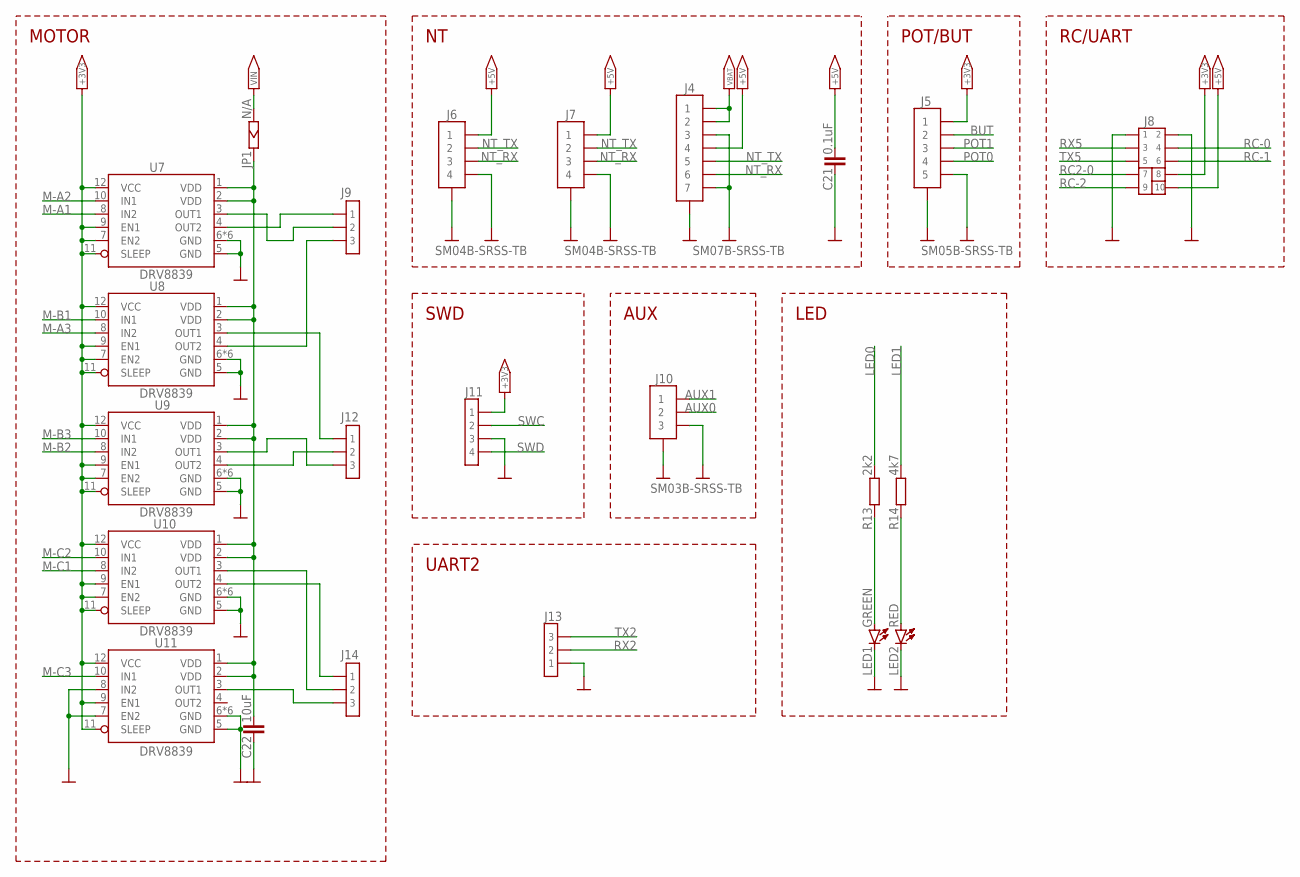
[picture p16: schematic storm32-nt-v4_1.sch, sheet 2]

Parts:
C21: 0.1uF; 0402[1005-METRIC]
C22: 10uF; 1206[3216-METRIC]; VOLTAGE 63; MOUSER 81-GRM32ER71J106MA2L
J4: SM07B-SRSS-TB
J5: SM05B-SRSS-TB
J6, J7: SM04B-SRSS-TB
J8: HEADER; 2X5
J9, J12, J13, J14: HEADER_THT_2.54X1N_MALE-03-2.54-2.54; HEADER_THT_2.54X1N_MALE-03
J10: SM03B-SRSS-TB
J11: HEADER_THT_1.27X1N_MALE-04-1.27-1.27; HEADER_THT_1.27X1N_MALE-04
JP1: N/A; 0603[1608-METRIC]-0OHM-OFF
LED1: GREEN; 0603[1608-METRIC]-DIODE
LED2: RED; 0603[1608-METRIC]-DIODE
R13: 2k2; 0402[1005-METRIC]
R14: 4k7; 0402[1005-METRIC]
U7, U8, U9, U10, U11: DRV8839; WSON12

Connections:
+3V3: J5.1, J8.8, J11.1, U7.7 (EN2), U7.9 (EN1), U7.11 (SLEEP), U7.12 (VCC), U8.7 (EN2), U8.9 (EN1), U8.11 (SLEEP), U8.12 (VCC), U9.7 (EN2), U9.9 (EN1), U9.11 (SLEEP), U9.12 (VCC), U10.7 (EN2), U10.9 (EN1), U10.11 (SLEEP), U10.12 (VCC), U11.9 (EN1), U11.11 (SLEEP), U11.12 (VCC); also elsewhere on the board
+5V: C21.P$1 (1), J4.4, J6.1, J7.1, J8.10; also elsewhere on the board
AUX0: J10.2; also elsewhere on the board
AUX1: J10.1; also elsewhere on the board
BUT: J5.2; also elsewhere on the board
GND: C21.P$2 (2), C22.P$2 (2), J4.3, J4.7, J4.FIT@1, J4.FIT@2, J5.5, J5.FIT@1, J5.FIT@2, J6.4, J6.FIT@1, J6.FIT@2, J7.4, J7.FIT@1, J7.FIT@2, J8.1, J8.2, J10.3, J10.FIT@1, J10.FIT@2, J11.3, J13.1, LED1.C, LED2.C, U7.5 (GND), U7.6 (GND), U7.GND1 (GND), U7.GND2 (GND), U7.GND3 (GND), U7.GND4 (GND), U7.GND5 (GND), U8.5 (GND), U8.6 (GND), U8.GND1 (GND), U8.GND2 (GND), U8.GND3 (GND), U8.GND4 (GND), U8.GND5 (GND), U9.5 (GND), U9.6 (GND), U9.GND1 (GND), U9.GND2 (GND), U9.GND3 (GND), U9.GND4 (GND), U9.GND5 (GND), U10.5 (GND), U10.6 (GND), U10.GND1 (GND), U10.GND2 (GND), U10.GND3 (GND), U10.GND4 (GND), U10.GND5 (GND), U11.5 (GND), U11.6 (GND), U11.7 (EN2), U11.8 (IN2), U11.GND1 (GND), U11.GND2 (GND), U11.GND3 (GND), U11.GND4 (GND), U11.GND5 (GND); also elsewhere on the board
LED0: R13.P$2; also elsewhere on the board
LED1: R14.P$2; also elsewhere on the board
M-A1: U7.8 (IN2); also elsewhere on the board
M-A2: U7.10 (IN1); also elsewhere on the board
M-A3: U8.8 (IN2); also elsewhere on the board
M-B1: U8.10 (IN1); also elsewhere on the board
M-B2: U9.8 (IN2); also elsewhere on the board
M-B3: U9.10 (IN1); also elsewhere on the board
M-C1: U10.8 (IN2); also elsewhere on the board
M-C2: U10.10 (IN1); also elsewhere on the board
M-C3: U11.10 (IN1); also elsewhere on the board
unnamed: LED1.A, R13.P$1
unnamed: C22.P$1 (1), JP1.P$2, U7.1 (VDD), U7.2 (VDD), U8.1 (VDD), U8.2 (VDD), U9.1 (VDD), U9.2 (VDD), U10.1 (VDD), U10.2 (VDD), U11.1 (VDD), U11.2 (VDD)
unnamed: LED2.A, R14.P$1
unnamed: J9.1, U7.4 (OUT2)
unnamed: J9.2, U7.3 (OUT1)
unnamed: J9.3, U8.4 (OUT2)
unnamed: J12.1, U8.3 (OUT1)
unnamed: J12.2, U9.4 (OUT2)
unnamed: J12.3, U9.3 (OUT1)
unnamed: J14.2, U10.3 (OUT1)
unnamed: J14.1, U10.4 (OUT2)
unnamed: J14.3, U11.3 (OUT1)
NT_RX: J4.6, J6.3, J7.3; also elsewhere on the board
NT_TX: J4.5, J6.2, J7.2; also elsewhere on the board
POT0: J5.4; also elsewhere on the board
POT1: J5.3; also elsewhere on the board
RC2-0: J8.7; also elsewhere on the board
RC-0: J8.4; also elsewhere on the board
RC-1: J8.6; also elsewhere on the board
RC-2: J8.9; also elsewhere on the board
RX2: J13.2; also elsewhere on the board
RX5: J8.3; also elsewhere on the board
SWC: J11.2; also elsewhere on the board
SWD: J11.4; also elsewhere on the board
TX2: J13.3; also elsewhere on the board
TX5: J8.5; also elsewhere on the board
VBAT: J4.1, J4.2; also elsewhere on the board
VIN: JP1.P$1; also elsewhere on the board

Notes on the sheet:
MOTOR
POT/BUT
SWD
AUX
UART2
LED
RC/UART

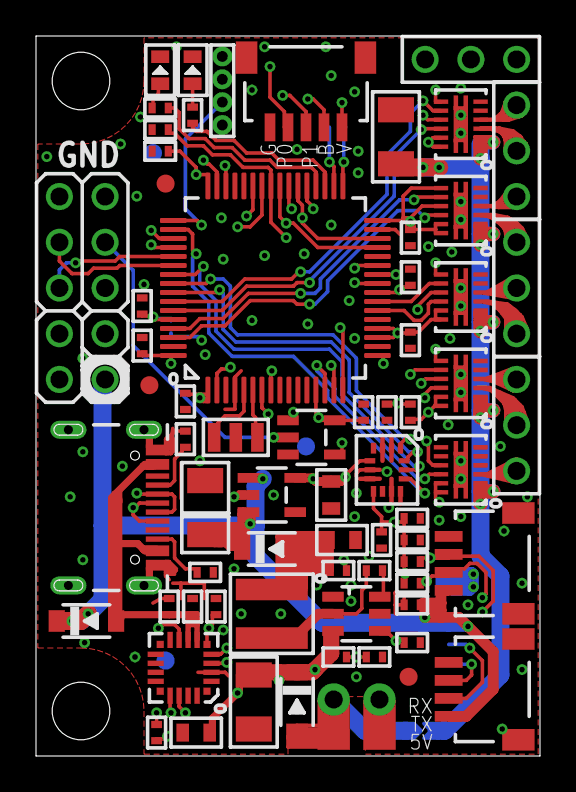
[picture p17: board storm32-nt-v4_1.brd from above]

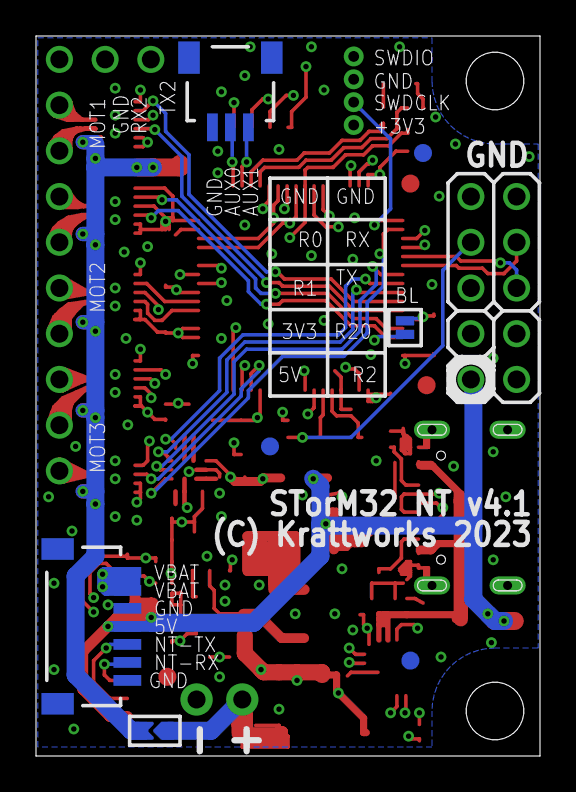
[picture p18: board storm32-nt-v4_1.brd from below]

Board: 4 copper layers, 28.0 x 40.0 mm, 77 parts (7 on the bottom side), 69 nets.

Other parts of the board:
FRAMEBRD1: A5L-LOC

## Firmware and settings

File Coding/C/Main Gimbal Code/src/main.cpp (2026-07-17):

#include <Arduino.h>
#include <HardwareSerial.h>
#include <BLEDevice.h>
#include <BLEUtils.h>
#include <BLEScan.h>
#include <BLEAdvertisedDevice.h>
#include <BLEClient.h>
#include <BLESecurity.h>
#include <WiFi.h>
#include <WebServer.h>
#include <Preferences.h>
#include <nvs_flash.h>
#include "STorM32_lib.h"

HardwareSerial storm32(1);
Preferences    prefs;

// ── Battery ────────────────────────────────────────────────
#define VOLT_OFFSET  12
#define PACKET_LEN   67

// ── RGB LED ────────────────────────────────────────────────
#define PIN_R        25
#define PIN_G        26
#define PIN_B        27

// ── Buttons ────────────────────────────────────────────────
#define BTN_MODE     18   // WiFi hotspot toggle
#define BTN_ACTION   19   // BLE shutter
#define DEBOUNCE_MS  20

// ── Joystick ───────────────────────────────────────────────
#define PIN_JOY_X    34   // ADC input-only
#define PIN_JOY_Y    35   // ADC input-only (adjacent to 34)
#define PIN_JOY_BTN  33   // Joystick push — toggles manual control

// ── STorM32 UART ───────────────────────────────────────────
#define STORM32_RX_PIN  16
#define STORM32_TX_PIN  17
#define STORM32_BAUD    115200

// ── WiFi Hotspot ───────────────────────────────────────────
#define WIFI_SSID    "ESP32-Gimbal"
#define WIFI_PASS    "gimbal1234"

// ── Sony BLE UUIDs ─────────────────────────────────────────
static BLEUUID SONY_SERVICE_UUID("8000FF00-FF00-FFFF-FFFF-FFFFFFFFFFFF");
static BLEUUID SONY_CHAR_UUID   ((uint16_t)0xFF01);

// ── HID UUIDs ─────────────────────────────────────────────
static BLEUUID HID_SERVICE_UUID ((uint16_t)0x1812);
static BLEUUID HID_REPORT_UUID  ((uint16_t)0x2A4D);

// ── Sony shutter commands ──────────────────────────────────
uint8_t CMD_FOCUS_DOWN[]   = { 0x01, 0x07 };
uint8_t CMD_SHUTTER_DOWN[] = { 0x01, 0x09 };
uint8_t CMD_SHUTTER_UP[]   = { 0x01, 0x08 };
uint8_t CMD_FOCUS_UP[]     = { 0x01, 0x06 };

// ── State ──────────────────────────────────────────────────
enum Mode       { MODE_BLUETOOTH, MODE_WIFI };
enum CameraType { CAM_SONY, CAM_HID, CAM_UNKNOWN };

Mode       currentMode = MODE_BLUETOOTH;
CameraType camType     = CAM_UNKNOWN;

String targetCameraName = "";
String connectedCamName = "";

float   batteryVoltage = 0.0f;
int     batteryPercent = -1;
uint8_t rxBuf[256];
int     rxLen          = 0;

// ── BLE ────────────────────────────────────────────────────
BLEClient*               pClient     = nullptr;
BLERemoteCharacteristic* pRemoteChar = nullptr;
BLEAdvertisedDevice*     myCamera    = nullptr;
bool bleConnected = false;
bool doConnect    = false;
bool doScan       = false;

// ── Web Server ─────────────────────────────────────────────
WebServer server(80);

// ── Debounce ───────────────────────────────────────────────
unsigned long lastPressMODE   = 0;
unsigned long lastPressACTION = 0;

// ── Scanned devices ────────────────────────────────────────
struct BLEDeviceInfo {
  String name;
  String address;
};
std::vector<BLEDeviceInfo> scannedDevices;

// ── Gimbal State ───────────────────────────────────────────
static bool     manual_control_enabled = false;
static uint16_t last_pitch_pwm         = 1500;
static uint16_t last_yaw_pwm           = 1500;
static uint16_t last_sent_raw_x        = 512;
static uint16_t last_sent_raw_y        = 512;

// Joystick button toggle state
static bool     joy_btn_held           = false;
static uint32_t joy_btn_press_ms       = 0;

static uint32_t debug_last_ms          = 0;

// ──────────────────────────────────────────────────────────
// BLE security callbacks
// ──────────────────────────────────────────────────────────
class SecurityCallbacks : public BLESecurityCallbacks {
  uint32_t onPassKeyRequest() {
    Serial.println("BLE: PassKey requested — returning 0");
    return 0;
  }
  void onPassKeyNotify(uint32_t pass_key) {
    Serial.printf("BLE: PassKey notify: %d\n", pass_key);
  }
  bool onConfirmPIN(uint32_t pass_key) {
    Serial.printf("BLE: Confirm PIN: %d — auto confirming\n", pass_key);
    return true;
  }
  bool onSecurityRequest() {
    Serial.println("BLE: Security request — accepting");
    return true;
  }
  void onAuthenticationComplete(esp_ble_auth_cmpl_t cmpl) {
    if (cmpl.success) {
      Serial.println("BLE: Pairing/bonding successful!");
    } else {
      Serial.printf("BLE: Pairing failed, reason: %d\n", cmpl.fail_reason);
    }
  }
};

// ──────────────────────────────────────────────────────────
// BLE client callbacks
// ──────────────────────────────────────────────────────────
class ClientCallbacks : public BLEClientCallbacks {
  void onConnect(BLEClient* pclient) {
    Serial.println("BLE: Client connected");
  }
  void onDisconnect(BLEClient* pclient) {
    bleConnected = false;
    pRemoteChar  = nullptr;
    Serial.println("BLE: Disconnected — will retry on next scan");
  }
};

// ──────────────────────────────────────────────────────────
// BLE scan callbacks
// ──────────────────────────────────────────────────────────
class ScanCallbacks : public BLEAdvertisedDeviceCallbacks {
  void onResult(BLEAdvertisedDevice device) {
    String name = device.getName().c_str();

    if (name.length() > 0) {
      bool exists = false;
      for (auto& d : scannedDevices) {
        if (d.address == device.getAddress().toString().c_str()) {
          exists = true;
          break;
        }
      }
      if (!exists) {
        BLEDeviceInfo info;
        info.name    = name;
        info.address = device.getAddress().toString().c_str();
        scannedDevices.push_back(info);
        Serial.printf("BLE found: %s (%s)\n", name.c_str(), info.address.c_str());
      }
    }

    bool nameMatch = targetCameraName.length() > 0 &&
                     name.equalsIgnoreCase(targetCameraName);

    bool sonyPairingOpen = false;
    if (device.haveManufacturerData()) {
      std::string mfr = device.getManufacturerData();
      if (mfr.length() >= 4 &&
          (uint8_t)mfr[0] == 0x2D && (uint8_t)mfr[1] == 0x01 &&
          (uint8_t)mfr[2] == 0x03 && (uint8_t)mfr[3] == 0x00) {
        for (size_t i = 4; i < mfr.length() - 1; i++) {
          if ((uint8_t)mfr[i] == 0x22 && (uint8_t)mfr[i+1] == 0xEF) {
            sonyPairingOpen = true;
            Serial.printf("Sony camera in pairing mode: %s\n", name.c_str());
            break;
          }
        }
      }
    }

    if (nameMatch || sonyPairingOpen) {
      BLEDevice::getScan()->stop();
      myCamera  = new BLEAdvertisedDevice(device);
      doConnect = true;
    }
  }
};

// ──────────────────────────────────────────────────────────
// Detect camera type
// ──────────────────────────────────────────────────────────
CameraType detectCameraType(String name) {
  name.toLowerCase();
  if (name.startsWith("ilce") || name.startsWith("zv-") ||
      name.startsWith("dsc-") || name.indexOf("sony") >= 0) {
    return CAM_SONY;
  }
  return CAM_HID;
}

// ──────────────────────────────────────────────────────────
// Connect to camera
// ──────────────────────────────────────────────────────────
bool connectToCamera() {
  Serial.printf("BLE: Connecting to %s...\n", myCamera->getName().c_str());

  BLEDevice::setSecurityCallbacks(new SecurityCallbacks());
  BLEDevice::setEncryptionLevel(ESP_BLE_SEC_ENCRYPT);

  BLESecurity* pSecurity = new BLESecurity();
  pSecurity->setAuthenticationMode(ESP_LE_AUTH_REQ_SC_BOND);
  pSecurity->setCapability(ESP_IO_CAP_NONE);
  pSecurity->setInitEncryptionKey(ESP_BLE_ENC_KEY_MASK | ESP_BLE_ID_KEY_MASK);
  pSecurity->setRespEncryptionKey(ESP_BLE_ENC_KEY_MASK | ESP_BLE_ID_KEY_MASK);

  pClient = BLEDevice::createClient();
  pClient->setClientCallbacks(new ClientCallbacks());

  if (!pClient->connect(myCamera)) {
    Serial.println("BLE: Connection failed");
    bleConnected = false;
    return false;
  }

  Serial.println("BLE: Connected — waiting for bonding to complete...");
  delay(2000);

  connectedCamName = myCamera->getName().c_str();
  camType          = detectCameraType(connectedCamName);

  if (camType == CAM_SONY) {
    BLERemoteService* pService = pClient->getService(SONY_SERVICE_UUID);
    if (!pService) {
      Serial.println("BLE: Sony service not found");
      Serial.println("     → Menu → Network → Bluetooth → Pairing");
      pClient->disconnect();
      bleConnected = false;
      return false;
    }
    pRemoteChar = pService->getCharacteristic(SONY_CHAR_UUID);
    if (!pRemoteChar) {
      Serial.println("BLE: Sony characteristic not found");
      pClient->disconnect();
      bleConnected = false;
      return false;
    }
    bleConnected = true;
    Serial.println("BLE: Sony camera ready!");
  } else {
    BLERemoteService* pService = pClient->getService(HID_SERVICE_UUID);
    if (!pService) {
      Serial.println("BLE: HID service not found");
      pClient->disconnect();
      bleConnected = false;
      return false;
    }
    pRemoteChar = pService->getCharacteristic(HID_REPORT_UUID);
    if (!pRemoteChar) {
      Serial.println("BLE: HID characteristic not found");
      pClient->disconnect();
      bleConnected = false;
      return false;
    }
    bleConnected = true;
    Serial.println("BLE: HID device ready!");
  }

  if (bleConnected && connectedCamName != targetCameraName) {
    targetCameraName = connectedCamName;
    prefs.begin("gimbal", false);
    prefs.putString("camname", targetCameraName);
    prefs.end();
    Serial.printf("Saved camera: %s\n", targetCameraName.c_str());
  }

  return bleConnected;
}

// ──────────────────────────────────────────────────────────
// Trigger shutter
// ──────────────────────────────────────────────────────────
void triggerShutter() {
  if (!bleConnected || pRemoteChar == nullptr) {
    Serial.println("BLE: Not connected");
    if (myCamera != nullptr || targetCameraName.length() > 0) {
      Serial.println("Retrying scan...");
      doScan = true;
    }
    return;
  }

  if (camType == CAM_SONY) {
    Serial.println("Shutter: Sony");
    pRemoteChar->writeValue(CMD_FOCUS_DOWN,   2, true); delay(50);
    pRemoteChar->writeValue(CMD_SHUTTER_DOWN, 2, true); delay(100);
    pRemoteChar->writeValue(CMD_SHUTTER_UP,   2, true); delay(50);
    pRemoteChar->writeValue(CMD_FOCUS_UP,     2, true);
    Serial.println("Shutter done");
  } else {
    Serial.println("Shutter: HID volume down");
    uint8_t keyDown[] = { 0x02, 0x00, 0x00, 0x00, 0x00, 0x00, 0x00, 0x00 };
    uint8_t keyUp[]   = { 0x00, 0x00, 0x00, 0x00, 0x00, 0x00, 0x00, 0x00 };
    pRemoteChar->writeValue(keyDown, 8, true); delay(100);
    pRemoteChar->writeValue(keyUp,   8, true);
    Serial.println("Shutter done");
  }
}

// ──────────────────────────────────────────────────────────
// Start BLE scan
// ──────────────────────────────────────────────────────────
void startScan() {
  scannedDevices.clear();
  Serial.println("BLE: Scanning...");
  BLEScan* pScan = BLEDevice::getScan();
  pScan->setAdvertisedDeviceCallbacks(new ScanCallbacks(), true);
  pScan->setActiveScan(true);
  pScan->start(5, false);
  Serial.printf("BLE: Scan done, found %d devices\n", scannedDevices.size());
}

// ──────────────────────────────────────────────────────────
// LiPo percentage lookup
// ──────────────────────────────────────────────────────────
float lipoPercent(float voltage) {
  float v = voltage / 3.0f;
  if (v >= 4.20f) return 100.0f;
  if (v >= 4.15f) return  95.0f;
  if (v >= 4.11f) return  90.0f;
  if (v >= 4.08f) return  85.0f;
  if (v >= 4.02f) return  80.0f;
  if (v >= 3.98f) return  75.0f;
  if (v >= 3.95f) return  70.0f;
  if (v >= 3.91f) return  65.0f;
  if (v >= 3.87f) return  60.0f;
  if (v >= 3.83f) return  55.0f;
  if (v >= 3.79f) return  50.0f;
  if (v >= 3.75f) return  45.0f;
  if (v >= 3.71f) return  40.0f;
  if (v >= 3.67f) return  35.0f;
  if (v >= 3.63f) return  30.0f;
  if (v >= 3.59f) return  25.0f;
  if (v >= 3.55f) return  20.0f;
  if (v >= 3.51f) return  15.0f;
  if (v >= 3.45f) return  10.0f;
  if (v >= 3.40f) return   5.0f;
  return 0.0f;
}

// ──────────────────────────────────────────────────────────
// RGB LED
// ──────────────────────────────────────────────────────────
void setColor(int r, int g, int b) {
  analogWrite(PIN_R, r);
  analogWrite(PIN_G, g);
  analogWrite(PIN_B, b);
}

void updateLED() {
  if (batteryPercent < 0) { setColor(0, 0, 0); return; }
  if (batteryPercent >= 50) {
    setColor(0, 255, 0);
  } else if (batteryPercent >= 20) {
    setColor(255, 150, 0);
  } else {
    static bool          blinkState = false;
    static unsigned long lastBlink  = 0;
    if (millis() - lastBlink > 500) {
      blinkState = !blinkState;
      lastBlink  = millis();
    }
    blinkState ? setColor(255, 0, 0) : setColor(0, 0, 0);
  }
}

// ──────────────────────────────────────────────────────────
// STorM32 gimbal commands
// ──────────────────────────────────────────────────────────
static void send_recenter() {
  if (Serial2.availableForWrite() <= 0) return;
  tSTorM32CmdSetAngles t;
  t.pitch = 0.0f;
  t.roll  = 0.0f;
  t.yaw   = 0.0f;
  t.flags = 0;
  t.type  = 0;
  storm32_finalize_CmdSetAngles(&t);
  Serial2.write((uint8_t*)&t, sizeof(t));
  Serial.println("[Gimbal] Sent RECENTER command.");
}

static void hold_last_position() {
  if (Serial2.availableForWrite() <= 0) return;
  tSTorM32CmdSetPitchRollYaw t;
  t.pitch = last_pitch_pwm;
  t.roll  = 1500;
  t.yaw   = last_yaw_pwm;
  storm32_finalize_CmdSetPitchRollYaw(&t);
  Serial2.write((uint8_t*)&t, sizeof(t));
  Serial.println("[Gimbal] Holding last manual position.");
}

static void send_joystick() {
  if (Serial2.availableForWrite() <= 0) return;

  uint16_t raw_x = analogRead(PIN_JOY_X);
  uint16_t raw_y = analogRead(PIN_JOY_Y);

  const uint16_t HYSTERESIS = 30;
  if (abs((int16_t)raw_x - (int16_t)last_sent_raw_x) < HYSTERESIS &&
      abs((int16_t)raw_y - (int16_t)last_sent_raw_y) < HYSTERESIS) {
    return;
  }

  uint16_t yaw_pwm   = 1350 + ((uint32_t)raw_y * 300) / 1023;
  uint16_t pitch_pwm = 1250 + ((uint32_t)raw_x * 500) / 1023;

  tSTorM32CmdSetPitchRollYaw t;
  t.pitch = pitch_pwm;
  t.roll  = 1500;
  t.yaw   = yaw_pwm;
  storm32_finalize_CmdSetPitchRollYaw(&t);
  Serial2.write((uint8_t*)&t, sizeof(t));

  last_sent_raw_x = raw_x;
  last_sent_raw_y = raw_y;
  last_pitch_pwm  = pitch_pwm;
  last_yaw_pwm    = yaw_pwm;
}

// ──────────────────────────────────────────────────────────
// Joystick button — press to toggle manual control on/off
// ──────────────────────────────────────────────────────────
static void handle_joy_btn() {
  bool pressed = (digitalRead(PIN_JOY_BTN) == LOW);
  uint32_t now = millis();

  if (pressed && !joy_btn_held) {
    joy_btn_held     = true;
    joy_btn_press_ms = now;
  }

  if (!pressed && joy_btn_held) {
    if ((now - joy_btn_press_ms) >= DEBOUNCE_MS) {
      manual_control_enabled = !manual_control_enabled;
      if (manual_control_enabled) {
        Serial.println("[Gimbal] Joystick btn -> MANUAL CONTROL ON");
      } else {
        hold_last_position();
        Serial.println("[Gimbal] Joystick btn -> MANUAL CONTROL OFF — holding position");
      }
    }
    joy_btn_held = false;
  }
}

static void debug_gimbal_status() {
  uint32_t now = millis();
  if (now - debug_last_ms < 500) return;
  debug_last_ms = now;
  uint16_t raw_x = analogRead(PIN_JOY_X);
  uint16_t raw_y = analogRead(PIN_JOY_Y);
  Serial.printf("[Gimbal] X=%4u Y=%4u | PITCH=%4u YAW=%4u | MANUAL=%s | TX_FREE=%u\n",
                raw_x, raw_y,
                (uint16_t)(1250 + ((uint32_t)raw_x * 500) / 1023),
                (uint16_t)(1350 + ((uint32_t)raw_y * 300) / 1023),
                manual_control_enabled ? "ON" : "OFF",
                Serial2.availableForWrite());
}
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
void loop() {
  // ── BLE scan ──────────────────────────────────────────
  if (doScan) {
    doScan = false;
    startScan();
  }

  // ── BLE connect ───────────────────────────────────────
  if (doConnect) {
    doConnect = false;
    connectToCamera();
  }

  // ── Mode button (GPIO18) — toggle WiFi hotspot ────────
  if (digitalRead(BTN_MODE) == LOW &&
      millis() - lastPressMODE > DEBOUNCE_MS) {
    lastPressMODE = millis();
    if (currentMode == MODE_BLUETOOTH) {
      WiFi.mode(WIFI_AP);
      WiFi.softAP(WIFI_SSID, WIFI_PASS);
      setupWebServer();
      currentMode = MODE_WIFI;
      Serial.printf("WiFi hotspot on — SSID: %s\n", WIFI_SSID);
    } else {
      server.stop();
      WiFi.softAPdisconnect(true);
      currentMode = MODE_BLUETOOTH;
      Serial.println("WiFi off — BLE active");
    }
  }

  // ── Shutter button (GPIO19) ───────────────────────────
  if (digitalRead(BTN_ACTION) == LOW &&
      millis() - lastPressACTION > DEBOUNCE_MS) {
    lastPressACTION = millis();
    triggerShutter();
  }

  // ── WiFi web server ───────────────────────────────────
  if (currentMode == MODE_WIFI) {
    server.handleClient();
  }

  // ── Auto retry BLE ────────────────────────────────────
  static unsigned long lastRetry = 0;
  if (!bleConnected && targetCameraName.length() > 0 &&
      millis() - lastRetry > 15000) {
    lastRetry = millis();
    Serial.println("BLE: Auto-retry scan...");
    doScan = true;
  }

  // ── Battery reading from STorM32 ──────────────────────
  static unsigned long lastRequest = 0;
  static unsigned long lastByte    = 0;

  if (millis() - lastRequest > 1000) {
    rxLen = 0;
    storm32.write('d');
    lastRequest = millis();
  }

  while (storm32.available() && rxLen < 255) {
    rxBuf[rxLen++] = storm32.read();
    lastByte = millis();
  }

  if (rxLen > 0 && millis() - lastByte > 50) {
    if (rxLen == PACKET_LEN) {
      uint16_t raw = rxBuf[VOLT_OFFSET] | (rxBuf[VOLT_OFFSET + 1] << 8);
      batteryVoltage = raw / 1000.0f;
      if (batteryVoltage >= 10.5f && batteryVoltage <= 13.0f) {
        batteryPercent = (int)lipoPercent(batteryVoltage);
        Serial.printf("Voltage: %.3fV | Battery: %d%%\n",
                      batteryVoltage, batteryPercent);
      } else {
        Serial.println("Invalid battery reading — check connection");
        batteryPercent = -1;
      }
    } else {
      Serial.printf("Wrong packet length: %d (expected %d)\n",
                    rxLen, PACKET_LEN);
    }
    rxLen = 0;
  }

  // ── Gimbal joystick ───────────────────────────────────
  handle_joy_btn();
  if (manual_control_enabled) {
    send_joystick();
  }
  debug_gimbal_status();

  // ── RGB status LED ────────────────────────────────────
  updateLED();

  delay(10);
}

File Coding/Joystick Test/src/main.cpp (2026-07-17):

#include <Arduino.h>
#include "JoystickModule.h"

// Joystick object
JoystickModule joystick(A0, A1, 2);

// LED pins
const uint8_t LED_RIGHT = 6;
const uint8_t LED_LEFT  = 7;
const uint8_t LED_UP    = 8;
const uint8_t LED_DOWN  = 9;

// Joystick center and dead zone
const int CENTER = 512;
const int DEADZONE = 80;

// Convert joystick distance from center into LED brightness (0 to 255)
int getBrightness(int value, int center, int deadzone, bool positiveDirection) {
    int distance;

    if (positiveDirection) {
        distance = value - center;   // right or up
    } else {
        distance = center - value;   // left or down
    }

    if (distance <= deadzone) {
        return 0;
    }

    distance = distance - deadzone;

    if (distance > (512 - deadzone)) {
        distance = 512 - deadzone;
    }

    return map(distance, 0, 512 - deadzone, 0, 255);
}

void setup() {
    Serial.begin(9600);
    Serial.println("THIS IS MY CURRENT PROJECT");
    joystick.begin();

    pinMode(LED_RIGHT, OUTPUT);
    pinMode(LED_LEFT, OUTPUT);
    pinMode(LED_UP, OUTPUT);
    pinMode(LED_DOWN, OUTPUT);
}

void loop() {
    JoystickData joy = joystick.read();

    // X axis controls left and right LEDs
    int rightBrightness = getBrightness(joy.x, CENTER, DEADZONE, true);
    int leftBrightness  = getBrightness(joy.x, CENTER, DEADZONE, false);

    // Y axis controls up and down LEDs
    // Some joystick modules are reversed on Y, so swap UP/DOWN if needed
    int upBrightness    = getBrightness(joy.y, CENTER, DEADZONE, true);
    int downBrightness  = getBrightness(joy.y, CENTER, DEADZONE, false);

    analogWrite(LED_RIGHT, rightBrightness);
    analogWrite(LED_LEFT, leftBrightness);
    analogWrite(LED_UP, upBrightness);
    analogWrite(LED_DOWN, downBrightness);

    Serial.print("X: ");
    Serial.print(joy.x);
    Serial.print(" Y: ");
    Serial.print(joy.y);
    Serial.print(" | R: ");
    Serial.print(rightBrightness);
    Serial.print(" L: ");
    Serial.print(leftBrightness);
    Serial.print(" U: ");
    Serial.print(upBrightness);
    Serial.print(" D: ");
    Serial.println(downBrightness);

    delay(20);
}

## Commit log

2026-07-17 Revise README for 3-Axis Camera Gimbal project
    Updated README to provide detailed project overview, features, test results, and hardware specifications for the 3-axis camera gimbal.
2026-07-17 Uploaded Files relevant to Repo
    Uploaded more files as update to the project
    [storm32-nt-v4_1.brd, storm32-nt-v4_1.kicad_pcb, storm32-nt-v4_1.kicad_sch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]
